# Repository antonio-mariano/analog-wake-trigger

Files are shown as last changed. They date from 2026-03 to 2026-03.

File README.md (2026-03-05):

# Analog Wake Trigger – Low‑Power Motion Detector for the *sleep‑monitor* Project

<p align="center">
  
  
</p>

A **compact analog module** that monitors the velostat pressure sensors used in the **[github.com/antonio-mariano/sleep-monitor](https://github.com/antonio-mariano/sleep-monitor)** project and generates a clean digital wake signal whenever movement is detected.  

Although designed specifically for integration with [*sleep-monitor*](https://github.com/antonio-mariano/sleep-monitor), the module can also be used in similar systems or as a standalone movement detector.

This README focuses on circuit assembly, usage, and integration.  
A detailed explanation of the circuit architecture, design rationale, and the analog techniques behind it is available at:
👉 [docs/design_notes.md](https://github.com/antonio-mariano/analog-wake-trigger/blob/main/docs/design_notes.md)

---

## 📌 Overview

In the original [*sleep-monitor*](https://github.com/antonio-mariano/sleep-monitor), the microcontroller must remain awake to continuously read the sensors, which results in high power consumption.  
The **analog-wake-trigger** solves this limitation by acting as a low‑power motion sentinel that consumes only **3 mA** while continuously monitoring the sensors.

This allows the microcontroller (MCU) to stay in deep‑sleep mode and wake only when relevant motion occurs.

High‑level operation:

- 1 — The module continuously monitors the velostat sensors.  
- 2 — When movement is detected, it generates a half‑second pulse (configurable).  
- 3 — This pulse wakes the microcontroller, which performs a full sensor reading (as in the original [*sleep-monitor*](https://github.com/antonio-mariano/sleep-monitor)) and then returns to sleep.  
- The microcontroller can temporarily place the velostat sensors in high impedance so they can be read without interference from the module.

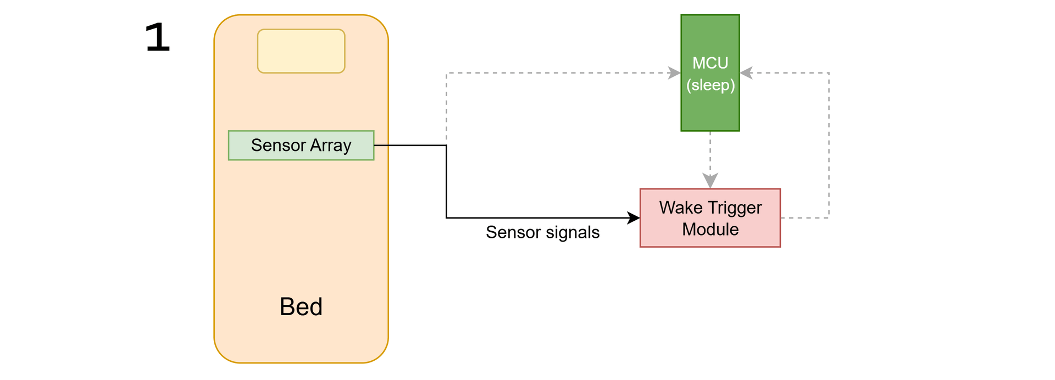
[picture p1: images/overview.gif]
Overview


---

## ✨ Features

- Compatible with both **3.3 V and 5 V** microcontrollers (can be powered directly from the MCU).  
- **Low power consumption** (~3 mA), ideal for battery‑powered systems.  
- **Generates a clean digital pulse** to wake a microcontroller from deep sleep.  
- **Adjustable detection threshold** via potentiometer for sensitivity tuning.  
- Designed as a **companion module** for the sleep-monitor project.  
- Can also operate as a **standalone movement detector**, where the output pulse simply indicates “movement detected”.

---

## 🧩 Components

The circuit was designed to minimize component count and use common, easy‑to‑source parts.

| Category | Component / Value | Qty |
|---|---|-----|
| **Sensor** | Velostat matrix (2×2) | 1 |
| **Semiconductors** | BC337 (NPN) | 5 |
| | BC327 (PNP) | 1 |
| | 1N4148 diode | 4 |
| | LM393 comparator | 2 |
| | NE555 timer | 1 |
| **Resistors** | 1.5 kΩ | 2 |
| | 10 kΩ | 7 |
| | 18 kΩ | 4 |
| | 470 kΩ | 5 |
| | 1.2 MΩ | 2 |
| | 10 kΩ potentiometer | 1 |
| **Capacitors**  | 0.01 µF | 1 |
| | 1 µF | 3 |
| | 10 µF | 2 |

---

## 🔌 Circuit Assembly

The module is composed of several analog stages that process the velostat signals and generate a clean digital wake pulse.  
These stages include filtering, amplification, threshold‑crossing detection and pulse generation.

A complete schematic (KiCad + PDF) is available in the `/hardware` directory.  
LTspice simulations and waveforms are available in `/hardware/ltspice`.
A detailed explanation of the circuit architecture, design rationale, and the analog techniques behind it is available at [docs/design_notes.md](https://github.com/antonio-mariano/analog-wake-trigger/blob/main/docs/design_notes.md)

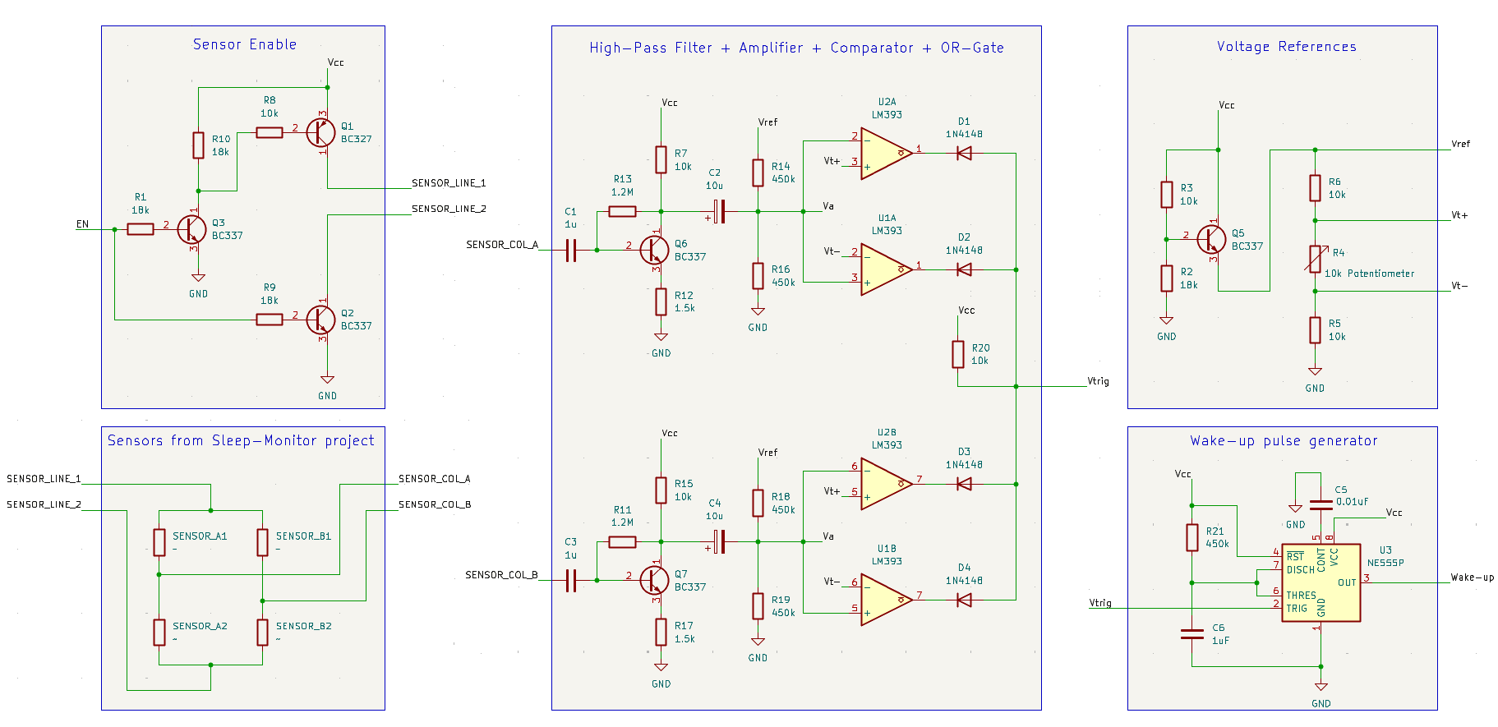
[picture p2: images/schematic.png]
Circuit Schematic KiCad


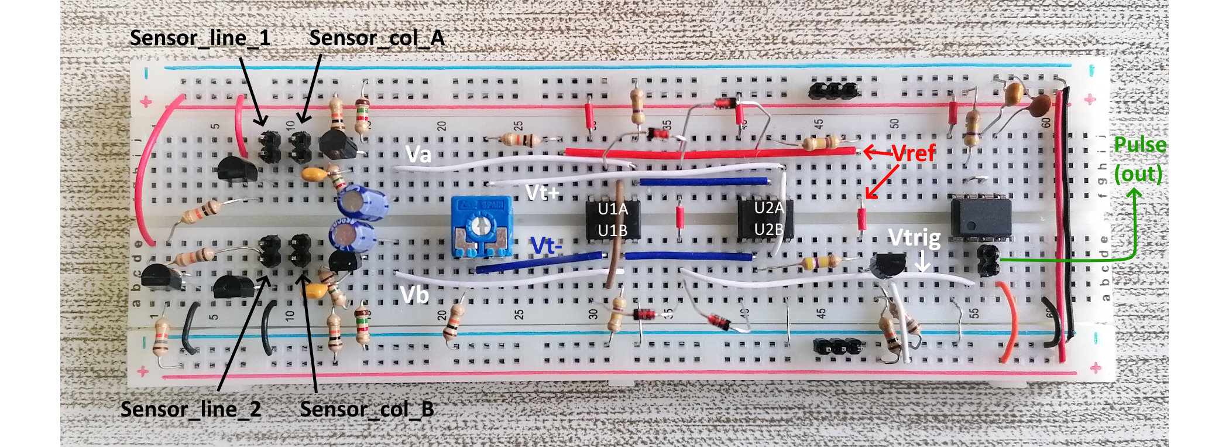
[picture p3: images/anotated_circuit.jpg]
Real circuit assembly (breadboard)


---
## 🚀 Practical Demonstration

To visualize the module in action, an LED was added to the MCU board to indicate when the analog‑wake‑trigger detects movement and wakes the microcontroller.

Real demonstration video

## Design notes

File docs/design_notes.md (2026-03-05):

# Design Notes

This document explains the design rationale and internal operation of the **analog‑wake‑trigger** module.  
While the main README focuses on usage and integration, this file describes *how* the circuit works and *why* specific design choice was made.

Real circuit image

---

## System Overview

### The circuit performs five main functions:
1. High‑pass filtering of the velostat sensor signals  
2. Amplification of filtered signals
3. Threshold cross detection using comparators  
4. Generation of a clean, fixed‑duration digital pulse using a monostable NE555  
5. Switching the sensors into a high‑impedance state so the MCU can read them without interference from the module  

Additionally, the circuit must generate several internal voltage references, described in:

6. Voltage References

---

## 1. High‑Pass Filtering

### Design goals
- Cutoff frequency high enough to ignore breathing  
- Low enough to detect body movement  
- Minimal component count  

### Design notes
- The base capacitor together with the BJT amplifier forms a high‑pass filter with a simulated cutoff frequency of about 1.2 Hz, which worked well with the real circuit.
- The collector signal must then be centered at Vref/2 so it sits halfway between Vt+ and Vt− (the comparator thresholds).
- This is achieved using a 10 µF coupling capacitor and a 470 kΩ–470 kΩ divider, which form a second high‑pass stage.
- This second stage must have a cutoff frequency much lower than 1.2 Hz to preserve a first‑order response.
- Its cutoff frequency is Fc = 1/(2pi*235kΩ * 10uF) = 0.07 Hz.

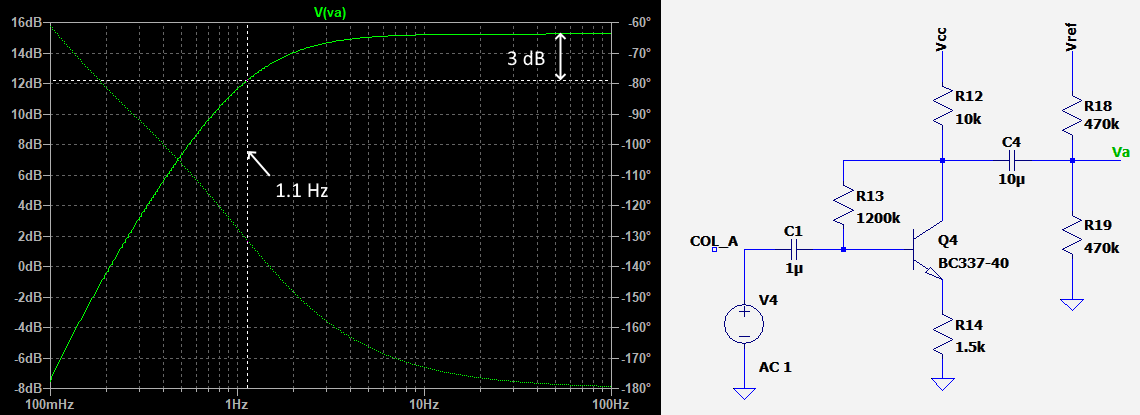
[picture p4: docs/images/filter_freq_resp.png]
High-Pass filter


---

## 2. Amplification Stage (NPN Transistor)

### Design goals
- A BJT amplifier was chosen instead of an op‑amp because it is simpler and avoids the need for a dual‑supply rail, allowing direct power from the MCU.
- A virtual ground using an RC divider could emulate an op‑amp midpoint, but at such low frequencies the required capacitor would be very large. The BJT amplifier avoids this issue.

### Design notes
- The purpose of the amplification is to increase the separation between Vt+ and Vt− (see section 6. Voltage References), so small mismatches between the Vref divider (10 kΩ – 10 kΩ potentiometer – 10 kΩ) and the HPF reference divider (470 kΩ – 470 kΩ) are not critical.

---

## 3. Comparators and Diode OR‑Gate

### Design goals
- The LM393 was chosen because it is widely available and operates from a 3 V supply, making it compatible with both 3.3 V and 5 V MCUs.
- Its open‑collector outputs make it ideal for the diode‑OR logic stage that follows.

### Design notes
- The resting input signal sits at Vref/2.
- The midpoint between Vt+ and Vt− is also Vref/2 (ignoring resistor mismatch).
- Whenever the signal exceeds Vt+ or drops below Vt−, the corresponding comparator pulls its output LOW (~0 V).
- Any LOW output forward‑biases its diode and pulls Vtrig LOW (~0.7 V), effectively implementing an OR logic gate.

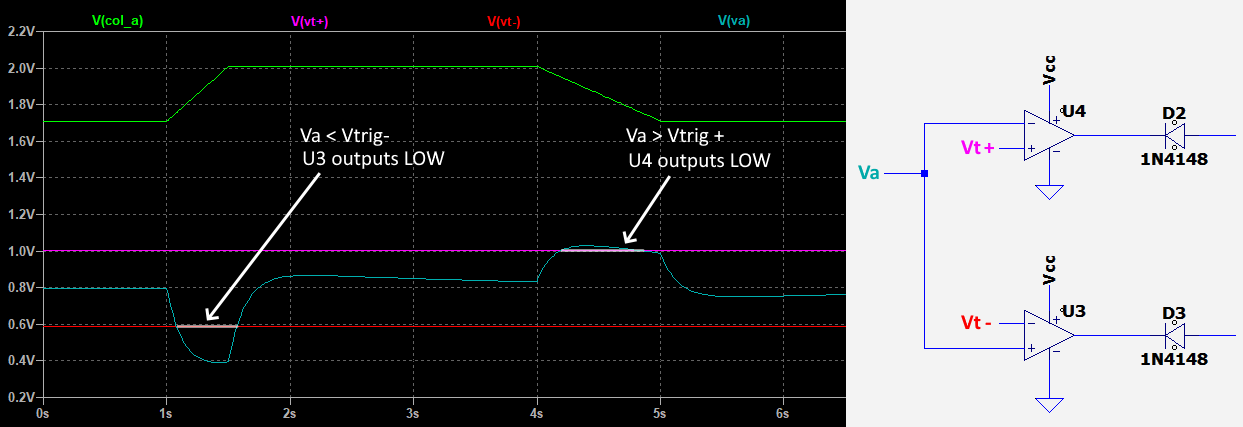
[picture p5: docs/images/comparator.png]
Comparator


---

## 4. Pulse Generation (NE555 Monostable)

Movement events are often short and irregular. To ensure the microcontroller reliably wakes, the comparator output triggers a **monostable NE555**.

The 555 provides:
- A clean digital pulse  
- Fixed duration (adjustable; with 470 kΩ and 1 µF, T = 1.1RC ≈ 0.5 s)  
- Output independent of input pulse width  

This guarantees reliable MCU wake‑up even with noisy or brief motion events.

---

## 5. High‑Impedance Sensor Switching

- The sensors are powered through a PNP transistor on Vcc and an NPN transistor on GND.
- When these transistors are ON, the sensors are powered and form voltage dividers.
- When they are OFF, the sensors are effectively disconnected from the supply and become high‑impedance.
- Because the PNP is active‑LOW and the NPN is active‑HIGH, an additional NPN transistor is used as an inverter so the MCU’s EN signal can switch both devices simultaneously.

---

## 6. Voltage References

### Vref
- The LM393 only accepts input voltages between 0 V and Vcc − 2 V.  
  Vref ensures that all comparison thresholds remain within this valid range.
- The BJT base is biased at [18/(10+18)] * Vcc = 0.64*Vcc
- With a small base current, Vbe ~= 0.5V, so Vref = 0.64Vcc - 0.5
- Vref(Vcc=3.3) = 1.6V
- Vref(Vcc=5)  =  2.7V

### Vt+ and Vt−
- These are the comparator thresholds. When the amplified signal rises above Vt+ or falls below Vt−, the corresponding comparator output goes LOW.
- With the 10 kΩ – 10 kΩ potentiometer – 10 kΩ divider, Vt+ can reach at most two‑thirds of Vref, ensuring it stays below Vcc − 2 V for Vcc = 3.3 V (or higher).

---

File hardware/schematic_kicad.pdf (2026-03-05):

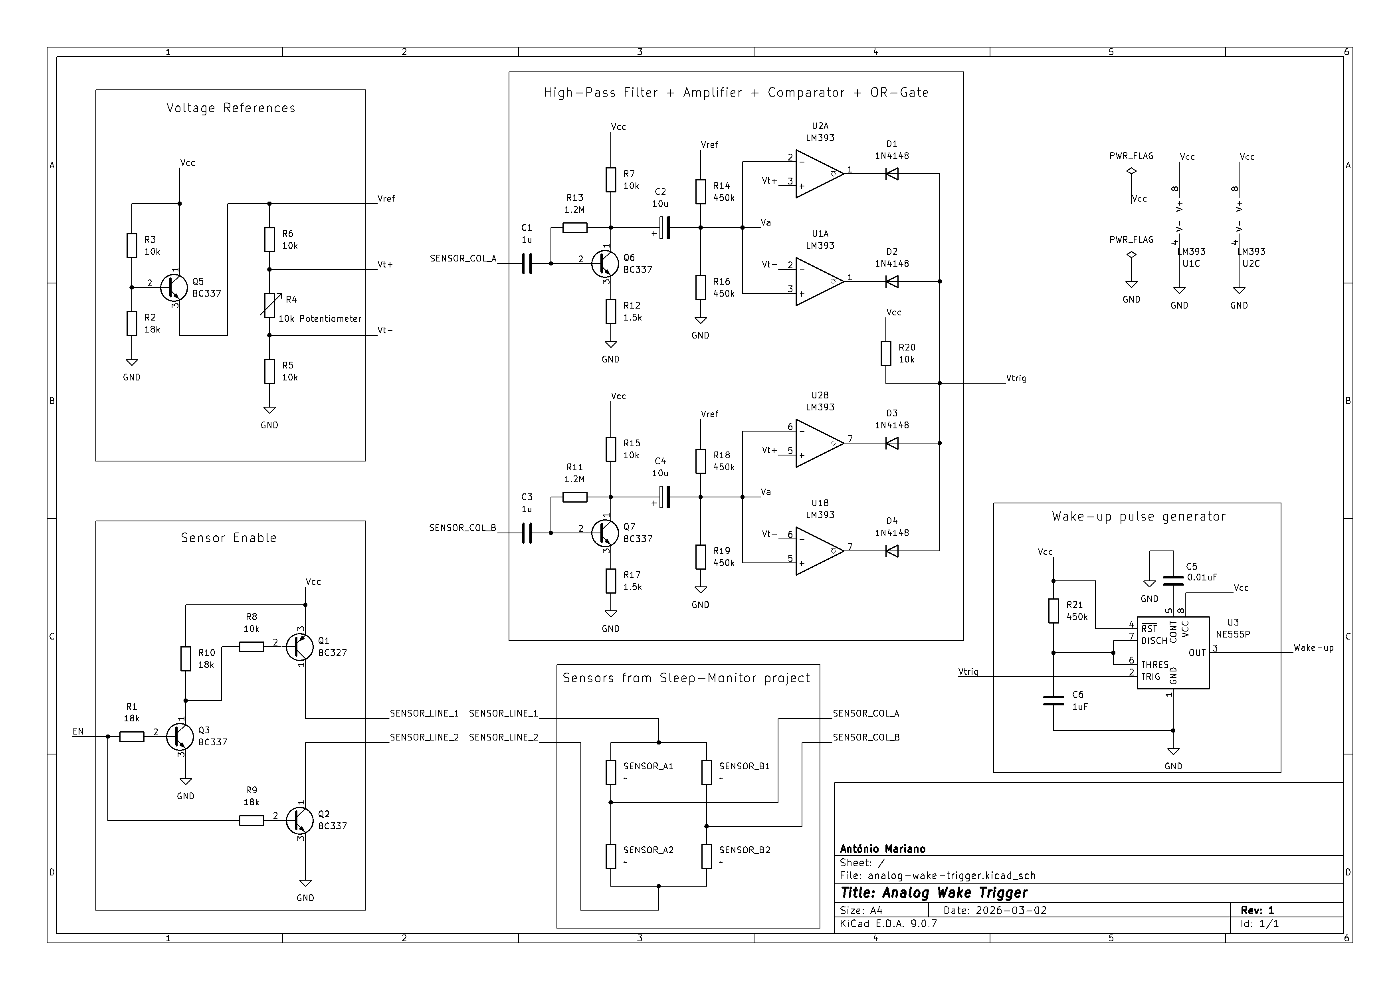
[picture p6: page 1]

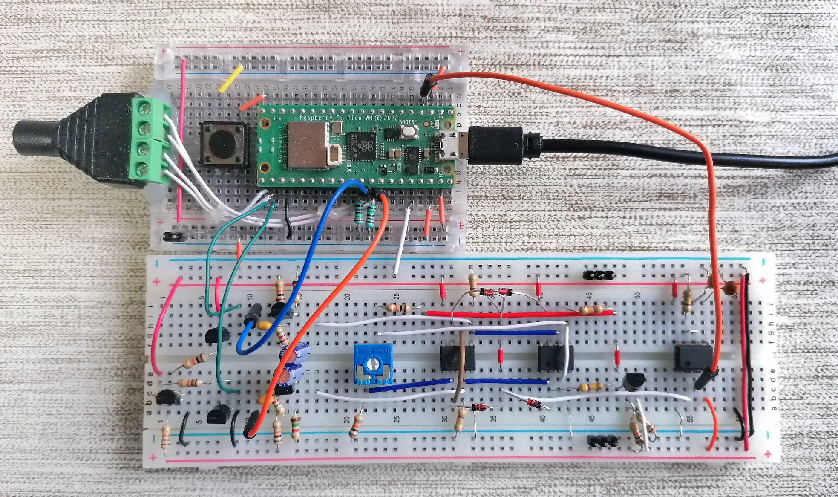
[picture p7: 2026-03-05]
images/circuit_with_sleep-monitor.jpg

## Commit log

2026-02-26 Enhance README with Analog Wake Trigger details
    Updated README.md to provide detailed information about the Analog Wake Trigger module, including its features, components, circuit assembly, and usage instructions.
2026-03-04 Revise design notes for analog-wake-trigger module
    Updated design notes for the analog-wake-trigger module, including detailed explanations of system functions, filtering, amplification, and microcontroller integration. Added sections on voltage refe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
2026-03-04 Revise design notes for analog-wake-trigger module
    Updated design notes for the analog-wake-trigger module, enhancing clarity and detail on circuit functions and design rationale.
2026-03-05 added comaprator and filter_fre simulation pngs
2026-03-05 Revise Components section with BOM details
    Updated components section to include detailed BOM list and improved clarity.
2026-03-05 Added schematic image
2026-03-05 added circuit and demo images
    [analog-wake-trigger.kicad_sch]
2026-03-05 edited circuit images
2026-03-05 Change circuit assembly image to annotated version
    Updated the image link for the real circuit assembly.
2026-03-05 Added anotated circuit image
2026-03-05 Enhance README with KiCad and LTspice badges
    Added badges for KiCad and LTspice to the README.
